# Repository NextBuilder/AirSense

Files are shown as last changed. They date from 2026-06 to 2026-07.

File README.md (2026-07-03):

<div align="center">

<br/>

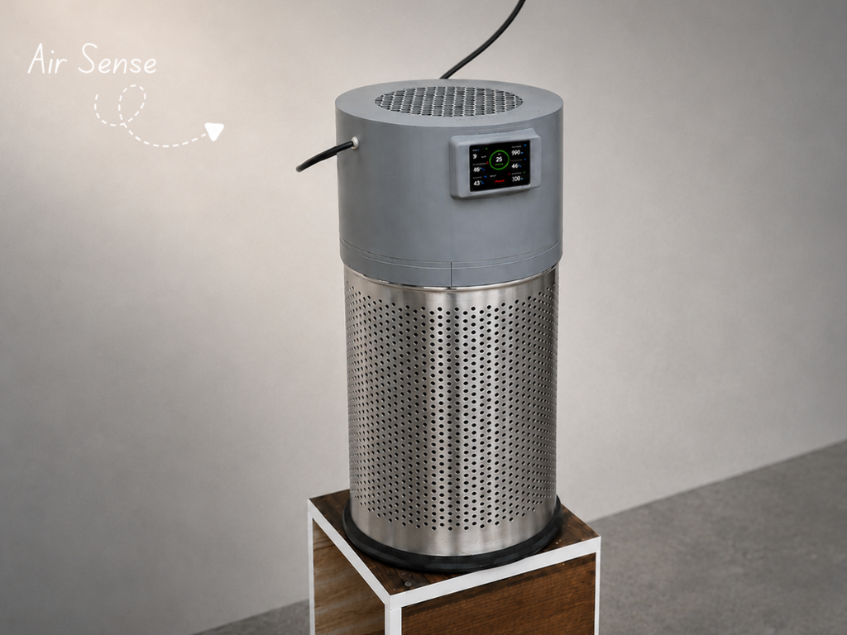
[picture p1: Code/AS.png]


<br/><br/>

# Air Sense

**The Smartest DIY Air Purifier — Engineered from Scratch**

<br/>

youtube (https://youtube.com/@NextBuilderIO)
instagram (https://instagram.com/next_builder)
x (https://x.com/NEXTBUILDERIO)
linkedin (https://www.linkedin.com/company/nextbuilderIO/)
instructables (https://www.instructables.com/member/Next%20Builder%20DIY/)
hackster (https://hackster.io/NEXTBUILDER)
hackaday (https://hackaday.io/NextBuilder)

<br/>

</div>

---

<br/>

## 🌿 Overview

Indoor air pollution is often invisible, yet it can significantly impact our health and comfort. **AirSense** is an open-source smart air purifier that combines real-time environmental monitoring, intelligent purification, and cloud connectivity into a single device.

Powered by the **Waveshare ESP32-S3**, AirSense continuously measures **PM2.5 dust levels, temperature, humidity, atmospheric pressure, and indoor air quality** using dedicated sensors. Live data is displayed on a modern **LVGL-powered TFT dashboard** and synchronized with **Arduino IoT Cloud**, allowing remote monitoring and fan control from anywhere.

Designed in **Autodesk Fusion**, the system features a custom 3D-printed enclosure, HEPA filtration, automatic fan control, and a product-like user experience. This repository includes everything needed to build your own AirSense, including source code, CAD files, circuit diagrams, and setup instructions.

<br/>

---

<br/>

## Live Display

<div align="center">
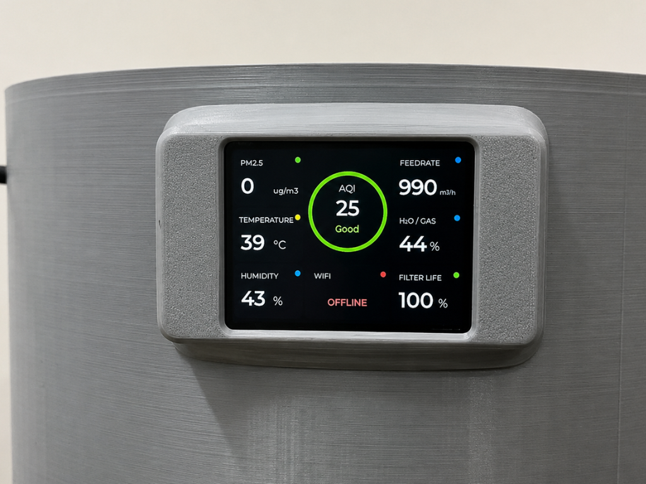
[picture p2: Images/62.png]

<br/><br/>
<sub>AirSense Live Dashboard — PM2.5 Dust · AQI · Temperature · Humidity · Air Quality · Feed Rate · Filter Health · Wi-Fi Status</sub>
</div>

<br/>

---

<br/>

## Demo

<div align="center">
<a href="https://www.youtube.com/watch?v=aSXS77vslJU">

</a>
<br/><br/>
<sub>▶ Click to watch the full build and demo on YouTube</sub>
</div>

<br/>

---

<br/>

## ✨ Features

**AirSense** combines intelligent air purification, environmental monitoring, and cloud connectivity into a single product-grade device. It continuously monitors **PM2.5 dust levels, AQI, temperature, humidity, atmospheric pressure, and indoor air quality** in real time, presenting all information through a beautiful **LVGL-powered dashboard**. The system uses a **Xiaomi Air Purifier 4 Lite HEPA filter**, capable of capturing up to **99.97% of airborne particles as small as 0.3 μm**, helping create a cleaner and healthier indoor environment.

Built around the **ESP32-S3**, AirSense synchronizes live data with **Arduino IoT Cloud**, enabling remote monitoring and control from anywhere through a smartphone, tablet, or web browser. The custom enclosure, designed in **Autodesk Fusion 360**, delivers a clean product-like appearance while maintaining easy assembly and maintenance. With complete source code, CAD files, circuit diagrams, and documentation included, AirSense is a fully open-source platform designed for learning, customization, and real-world everyday use.

<br/>

---

<br/>

## Enclosure Design

<div align="center">
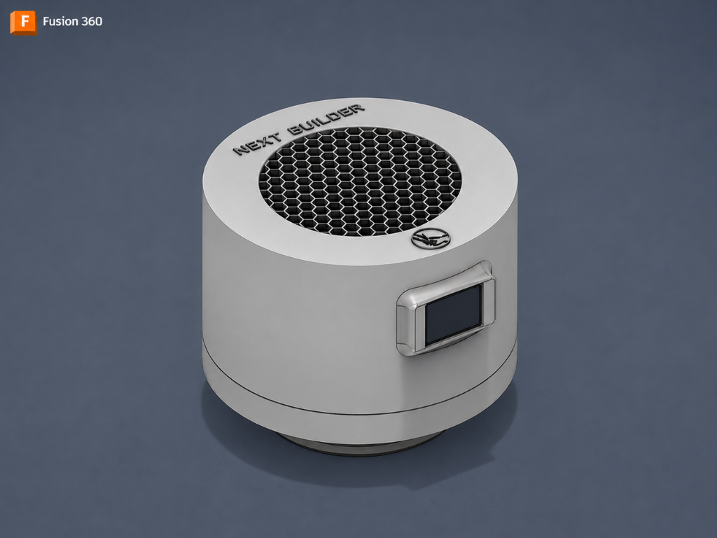
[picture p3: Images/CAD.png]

<br/><br/>
<sub>Fusion 360 CAD — cylindrical body · hexagonal intake grille · side-mounted TFT cutout · Next Builder branding</sub>
</div>

<br/>

The enclosure is designed around the **Xiaomi Air Purifier 4 Lite HEPA filter**, creating a compact and efficient airflow path. A **150mm high-airflow fan** is mounted at the top, drawing contaminated air through the filter and exhausting clean air upward. The **2.4-inch TFT display** is seamlessly integrated into a precision-cut side panel for a clean, product-like appearance. An **18L stainless steel dustbin** serves as the main structural body, providing excellent durability, a premium finish, and easy availability for replication.

<br/>

---

<br/>

## Bill of Materials

<div align="center">

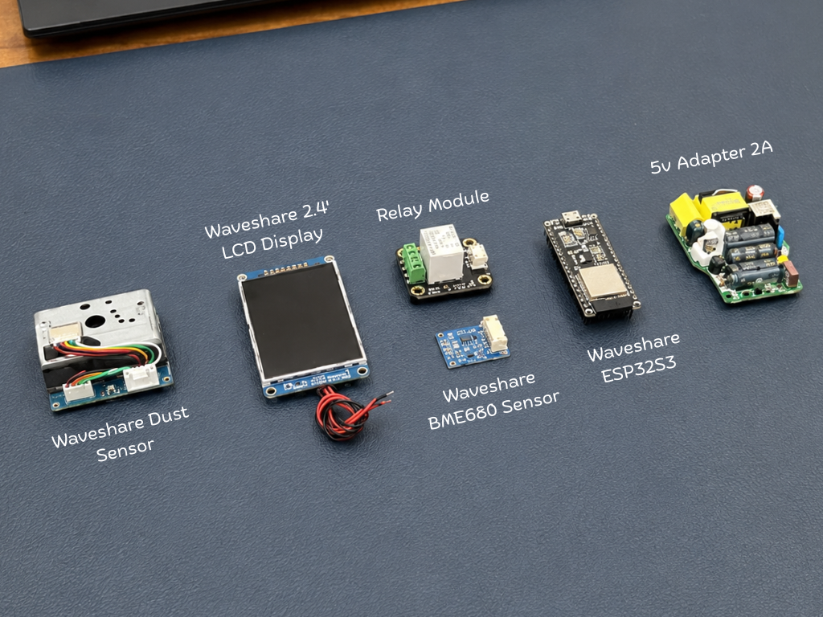
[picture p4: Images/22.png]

<br/>
<sub>All electronic components</sub>

<br/><br/>

<table>
<tr>
<td align="center" width="33%">
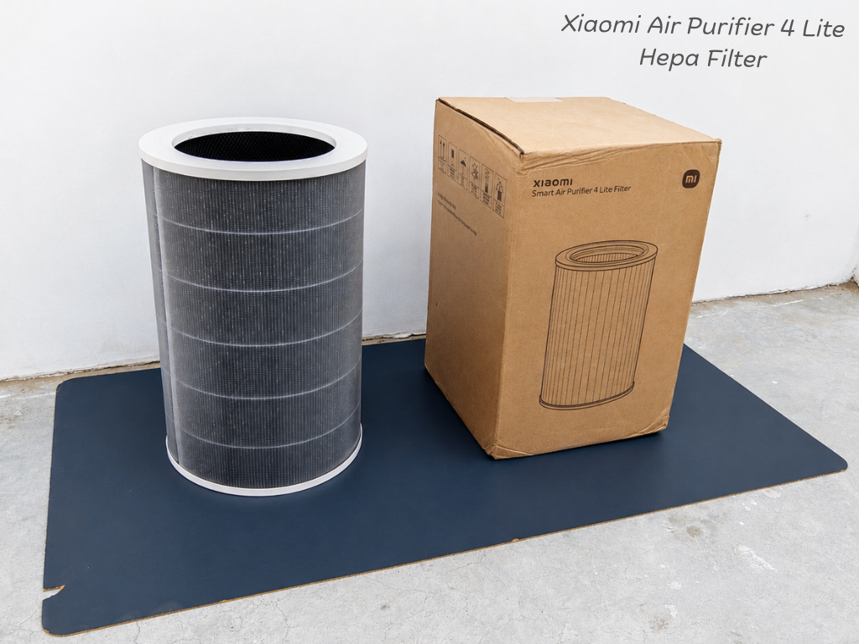
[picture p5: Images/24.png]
<br/><br/>
<b>Xiaomi Air Purifier 4 Lite</b><br/>
<sub>True HEPA Filter — 0.3 µm</sub>
</td>
<td align="center" width="33%">
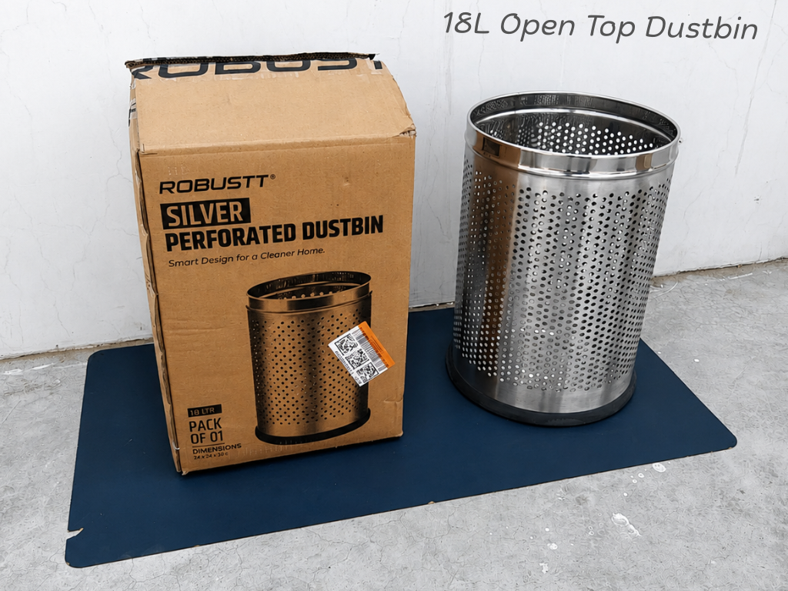
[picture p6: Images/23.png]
<br/><br/>
<b>18L Open-Top Steel Dustbin</b><br/>
<sub>Structural enclosure body</sub>
</td>
<td align="center" width="33%">
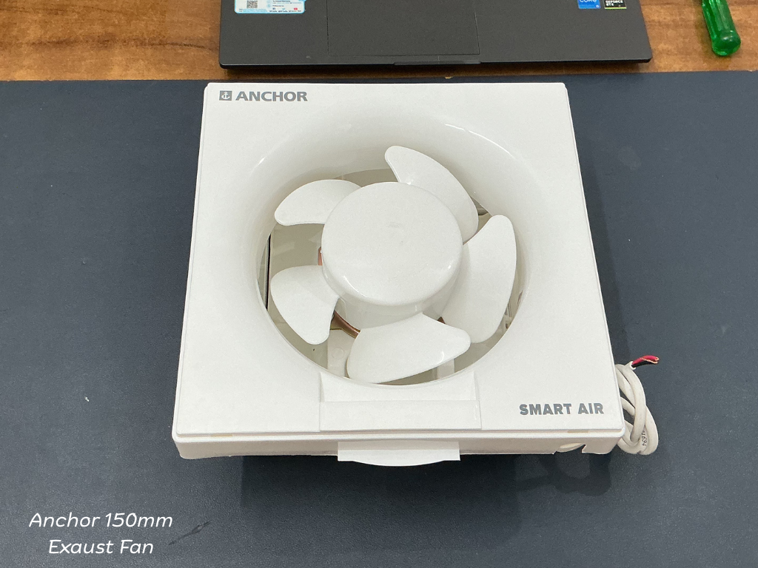
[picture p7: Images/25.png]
<br/><br/>
<b>Anchor 150mm Exhaust Fan</b><br/>
<sub>220V Smart Air — circulation</sub>
</td>
</tr>
</table>

</div>

<br/>

> Full BOM with purchase links is in the [Instructables tutorial →](https://www.instructables.com/AirSense-the-Smartest-DIY-Air-Purifier/)

<br/>

---

<br/>

## Internal Assembly

<div align="center">
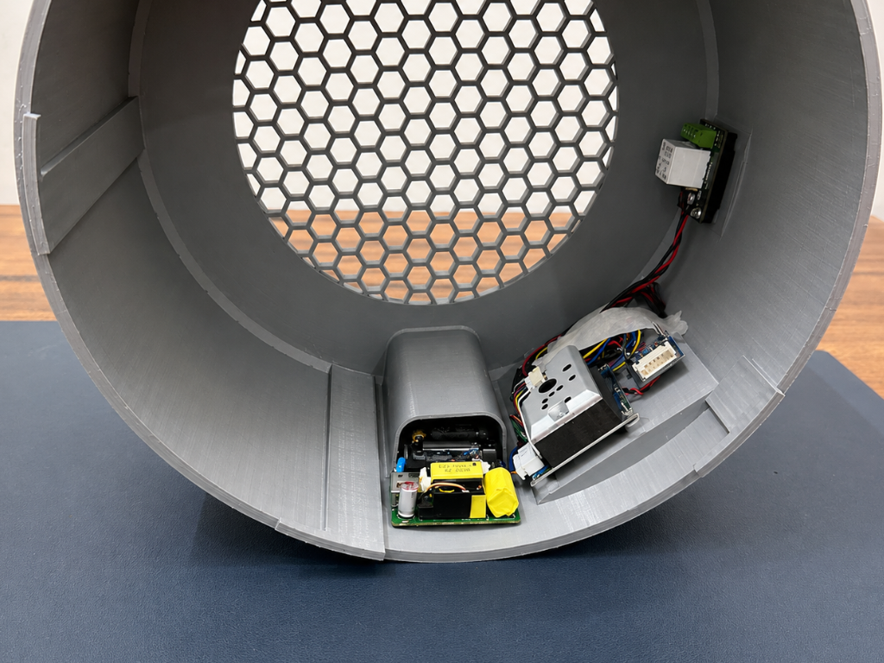
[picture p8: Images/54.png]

<br/><br/>
<sub>Inside view after complete wiring and assembly</sub>
</div>

<br/>

**Wiring Notes**

* The relay switches the **220V AC fan**, so always disconnect mains power before making any wiring changes or performing maintenance.
* The dust sensor relies on a precise LED pulse timing sequence for accurate measurements. The sampling logic used in the firmware should remain unchanged.
* The BME680 communicates via the **I²C interface**, using dedicated SDA and SCL connections on the ESP32-S3.
* The TFT display operates over **SPI**. Ensure all display pins, including CS, DC, and RST, match the assignments defined in the provided `User_Setup.h` file.
* Before powering the system, verify all power, signal, and ground connections to ensure safe and reliable operation.

<br/>

---

<br/>

## How It Works

AirSense continuously monitors the surrounding environment using dedicated air quality and environmental sensors. Every few seconds, the system measures **PM2.5 dust concentration, temperature, humidity, atmospheric pressure, and indoor air quality**, providing a real-time view of indoor environmental conditions.

The collected data is processed by the **ESP32-S3**, which calculates the Air Quality Index (AQI) and updates all measurements on the built-in **LVGL-powered dashboard**. Users can instantly view key air quality metrics through a clean and intuitive graphical interface. At the same time, sensor readings are synchronized with **Arduino IoT Cloud** over Wi-Fi, allowing remote monitoring from anywhere using a smartphone, tablet, or web browser.

The purification fan operates continuously to draw air through the **HEPA filtration system**, where dust and airborne particles are captured before clean air is released back into the environment. Users can manually turn the purifier on or off at any time using the **Arduino IoT Remote App**, providing convenient control from anywhere. By combining real-time monitoring, cloud connectivity, and continuous air purification, AirSense helps users better understand and improve the quality of the air they breathe every day.

<br/>

---

<br/>

## 📚 Build Guide & Documentation

Want to build your own **AirSense**? Complete step-by-step instructions, cloud configuration, wiring details, assembly photos, and testing procedures are available in the full written tutorials below.

Whether you're a beginner exploring IoT and air quality monitoring or an experienced maker looking to customize the design, these guides will walk you through the entire build process from start to finish.

### Tutorials & Project Documentation

* **Instructables**
  https://www.instructables.com/AirSense-the-Smartest-DIY-Air-Purifier/

* **Hackster.io**
  https://www.hackster.io/NEXTBUILDER/airsense-the-smartest-diy-air-purifier-f775f8

* **Hackaday.io**
  https://hackaday.io/project/205928-airsense-the-smartest-diy-air-purifier

* **ElectronicWings**
  https://www.electronicwings.com/users/NextBuilder/projects/6592/airsense---the-smartest-diy-air-purifier

All project resources, including firmware, CAD models, library configuration files, and circuit diagrams, are available in this GitHub repository.

---

<br/>

## License

Open for **personal and educational use only.**
Commercial use, resale, or redistribution in any product requires explicit written permission from the author.

<br/>

---

<br/>

<div align="center">

Built with ❤️ by **[Next Builder](https://youtube.com/@nextbuilderio)**

*Built one? Share it. Open an issue, tag us, drop a photo — the community makes this worth building.*

*⭐ Star this repo if it helped you build something awesome ⭐*

</div>

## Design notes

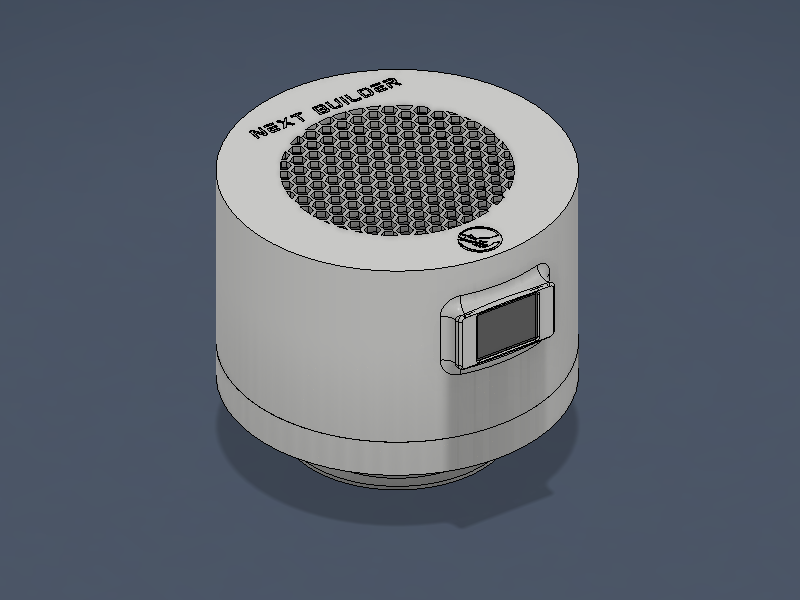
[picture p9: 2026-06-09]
CAD Design/Air Sense 01.png

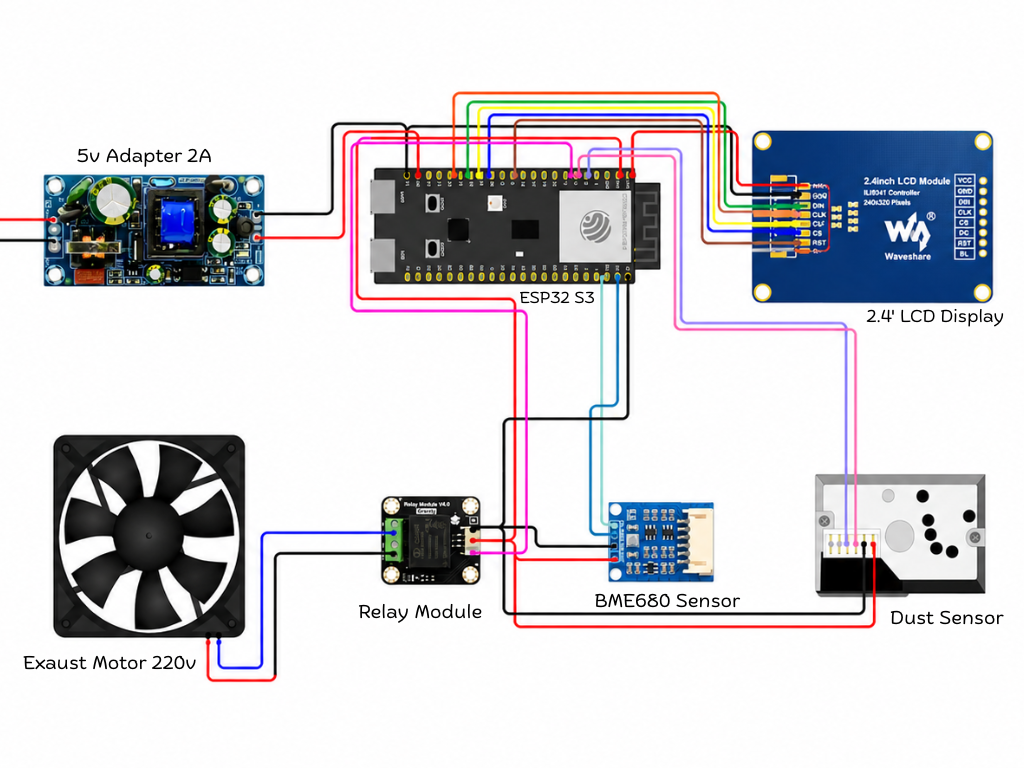
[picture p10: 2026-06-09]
Circuit Diagram/Connection Diagram.png

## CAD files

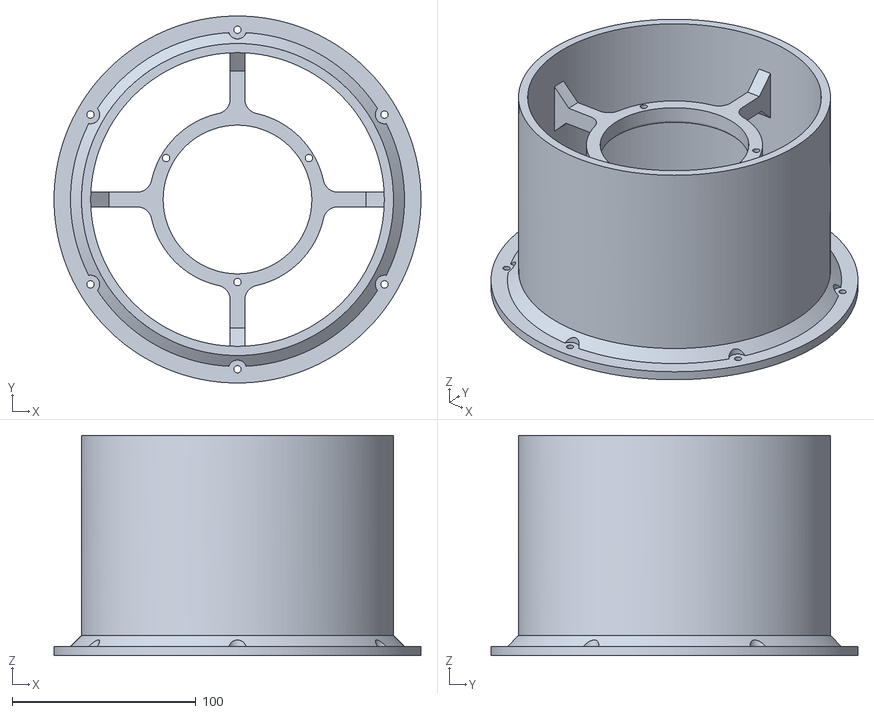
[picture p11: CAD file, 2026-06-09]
CAD Design/Motor Mount.stl
200.0 x 200.0 x 120.0

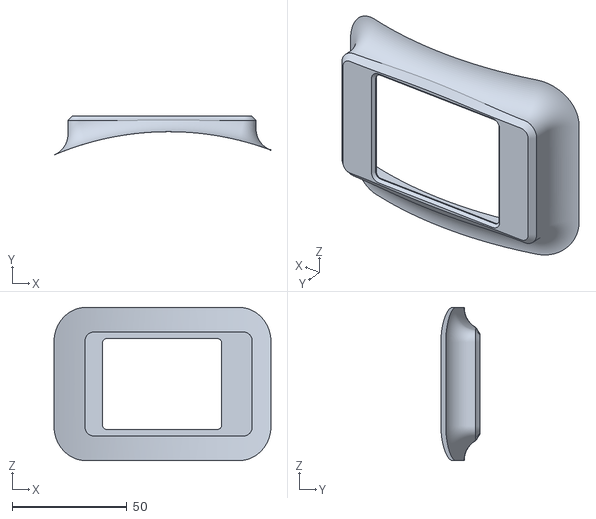
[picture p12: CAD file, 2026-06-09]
CAD Design/Display Cover.stl
94.6 x 17.1 x 66.7

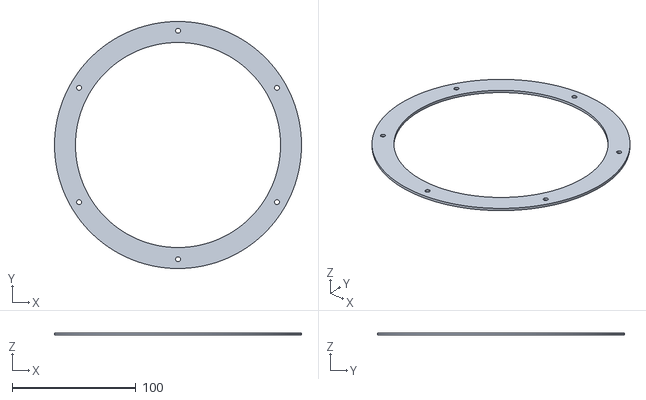
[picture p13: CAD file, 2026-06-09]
CAD Design/Gasket Seal.stl
200.0 x 200.0 x 2.00

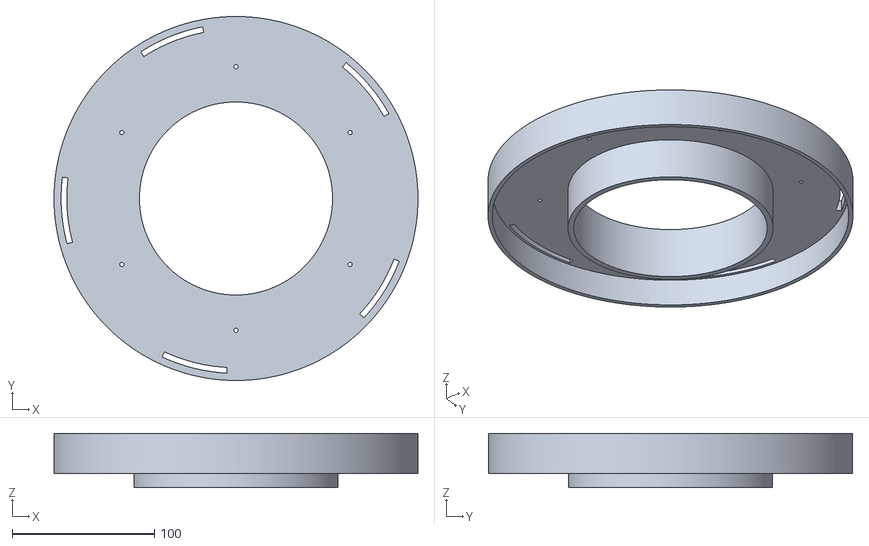
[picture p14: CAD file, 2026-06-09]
CAD Design/Bottom Plate.stl
255.5 x 255.5 x 38.0

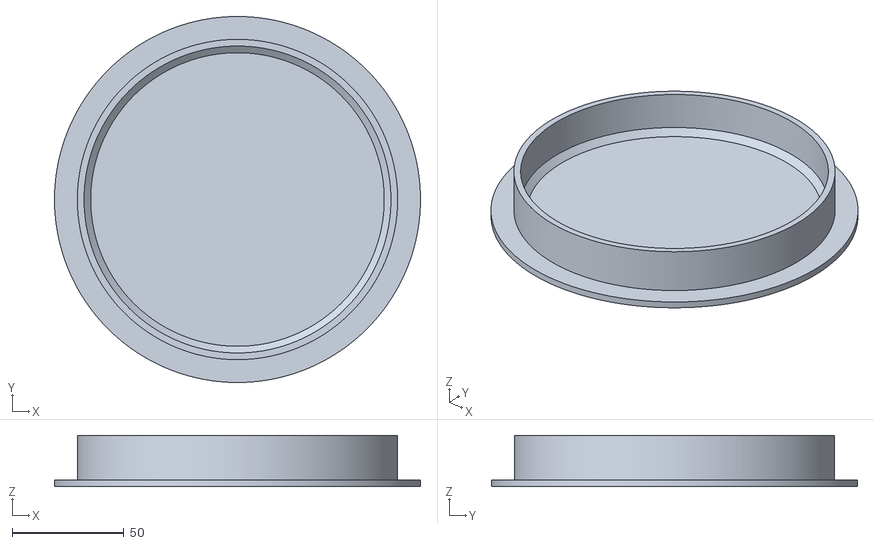
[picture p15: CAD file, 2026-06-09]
CAD Design/Filter Base.stl
164.0 x 164.0 x 23.0

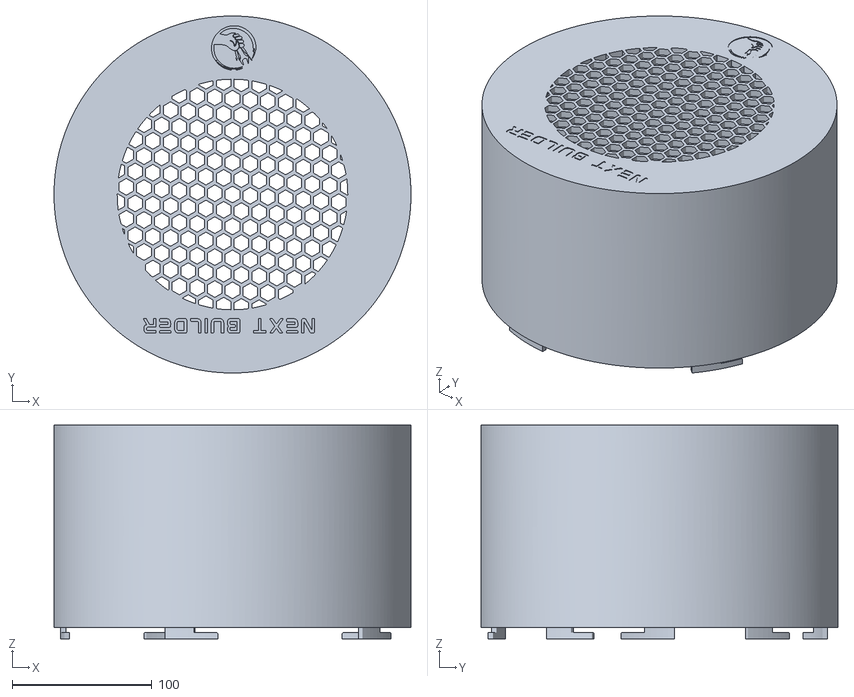
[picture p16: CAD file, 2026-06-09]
CAD Design/Housing.stl
255.5 x 255.5 x 153.0

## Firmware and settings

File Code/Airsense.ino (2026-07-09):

/**
 * ============================================================
 *  Air Sense: The Smartest DIY Air Purifier
 *  Author   : Kishan Pratap Singh
 *  Cloud    : Arduino IoT Cloud (Air Sense)
 * ============================================================
 */

// ===== INCLUDES =====
#include <Arduino.h>
#include <TFT_eSPI.h>
#include <lvgl.h>
#include <SPI.h>
#include <Adafruit_BME680.h>
#include <Wire.h>
#include <WiFi.h>
#include <ArduinoIoTCloud.h>
#include <Arduino_ConnectionHandler.h>

// ═══════════════════════════════════════════════════════════════
//  CONFIGURATION
// ═══════════════════════════════════════════════════════════════

// ── WiFi ──────────────────────────────────────────────────────
const char SSID[] = "Airtel_Nirmala Maa";
const char PASS[] = "Air@8090";

// ── IoT Cloud device credentials ───────────────────
const char THING_ID[]      = "Your_Client_ID";
const char DEVICE_LOGIN[]  = "your_device_name";              
const char DEVICE_KEY[]    = "Your_Client_Secret";

// ── Pin map ───────────────────────────────────────────────────
#define BME_SDA        43   // BME680 I2C SDA
#define BME_SCL        44   // BME680 I2C SCL

#define DUST_ILED_PIN   5   // Waveshare dust sensor — LED trigger
#define DUST_AOUT_PIN   6   // Waveshare dust sensor — analog output

#define RELAY_PIN       7   // Fan relay

// ── Polarity configuration ───────────────────────────────────
#define DUST_LED_ACTIVE_LOW 1
#if DUST_LED_ACTIVE_LOW
  #define DUST_LED_ON  LOW
  #define DUST_LED_OFF HIGH
#else
  #define DUST_LED_ON  HIGH
  #define DUST_LED_OFF LOW
#endif

#define RELAY_ACTIVE_LOW 0
#if RELAY_ACTIVE_LOW
  #define RELAY_ON  LOW
  #define RELAY_OFF HIGH
#else
  #define RELAY_ON  HIGH
  #define RELAY_OFF LOW
#endif

// ── Dust sensor calibration ──────────────────────────────────
#define DUST_SAMPLES                  15      
#define DUST_SENSITIVITY              200.0f  
#define DUST_SMOOTHING_ALPHA          0.3f    
#define DUST_DEFAULT_BASELINE         0.60f   
#define DUST_FLOOR_ADAPT_RATE         0.01f   
#define DUST_BOARD_VOLTAGE_MULTIPLIER 10.0f  
#define DUST_DEBUG                    1       

// ── BME680 gas sensor ─────────────────────────────────────────
#define BME_WARMUP_MS       300000UL  
#define IAQ_SMOOTHING_ALPHA 0.1f      

// ── Font fallback (if Inter fonts aren't generated) ──────────
#ifndef INTER_FONTS_AVAILABLE
  #define inter_bold_32    lv_font_montserrat_28
  #define inter_medium_14  lv_font_montserrat_10
  #define inter_regular_12 lv_font_montserrat_12
  #define inter_regular_16 lv_font_montserrat_14
#endif

// ═══════════════════════════════════════════════════════════════
//  DATA TYPES & AQI LOGIC
// ═══════════════════════════════════════════════════════════════

typedef struct {
  float pm25, temperature, humidity, pressure, iaq, filterLife;
  int   aqi;
  bool  wifiConnected;
} SensorData;

typedef struct { const char *label; lv_color_t color; } AQIStatus;

// EPA AQI categories, label text shortened to fit the dashboard circle.
static inline AQIStatus getAQIStatus(int aqi) {
  if (aqi <=  50) return {"Good",          lv_color_make(  0,228,  0)};   // Green
  if (aqi <= 100) return {"Moderate",      lv_color_make(255,255,  0)};   // Yellow
  if (aqi <= 150) return {"Unhealthy for\nSensitive Groups",
                                          lv_color_make(255,126,  0)};    // Orange
  if (aqi <= 200) return {"Unhealthy",     lv_color_make(255,  0,  0)};   // Red
  if (aqi <= 300) return {"Very Unhealthy",lv_color_make(143, 63,151)};   // Purple
  return              {"Hazardous",         lv_color_make(126,  0, 35)};    // Maroon
}

// EPA PM2.5 breakpoint table, extended through the Hazardous band
// (AQI 500) so severe pollution days display correctly.
static inline int calcAQI(float pm25, float iaq) {
  int p = 0;
  if      (pm25 <= 12.0f)   p = (int)(pm25 / 12.0f * 50);
  else if (pm25 <= 35.4f)   p = 51  + (int)((pm25 - 12.1f)  / 23.3f  * 49);
  else if (pm25 <= 55.4f)   p = 101 + (int)((pm25 - 35.5f)  / 19.9f  * 49);
  else if (pm25 <= 150.4f)  p = 151 + (int)((pm25 - 55.5f)  / 94.9f  * 49);
  else if (pm25 <= 250.4f)  p = 201 + (int)((pm25 - 150.5f) / 99.9f  * 99);
  else if (pm25 <= 500.4f)  p = 301 + (int)((pm25 - 250.5f) / 249.9f * 199);
  else                      p = 500;
  return (int)(p*0.7f + (100.f-iaq)*1.5f*0.3f);
}

// ═══════════════════════════════════════════════════════════════
//  UI THEME & LAYOUT CONSTANTS
// ═══════════════════════════════════════════════════════════════

#define CB    lv_color_hex(0x050505)
#define CC    lv_color_hex(0x111111)
#define CD    lv_color_hex(0x232323)
#define CW    lv_color_hex(0xFFFFFF)
#define CG    lv_color_hex(0x00DF50)
#define CGD1  lv_color_hex(0x003D18)
#define CGD2  lv_color_hex(0x001E0C)
#define CGD3  lv_color_hex(0x000D05)
#define CDIM  lv_color_hex(0x757575)
#define CR    10

#define CSW   96
#define CH    75
#define XL     2
#define XR   222
#define XC   101
#define WC   118
#define Y1     2
#define Y2    80
#define Y3   158

#define AQI_CX  160
#define AQI_CY   86
#define AQI_R   109

#define SCREEN_W 320
#define SCREEN_H 240
#define BUF_SIZE (SCREEN_W * 24)

// ═══════════════════════════════════════════════════════════════
//  DISPLAY & LVGL CORE
// ═══════════════════════════════════════════════════════════════

static lv_color_t buf1[BUF_SIZE];
static lv_color_t buf2[BUF_SIZE];
TFT_eSPI tft = TFT_eSPI();

void lvgl_flush_cb(lv_display_t *d, const lv_area_t *a, uint8_t *px) {
  tft.startWrite();
  tft.setAddrWindow(a->x1, a->y1, a->x2-a->x1+1, a->y2-a->y1+1);
  tft.pushColors((uint16_t*)px, (a->x2-a->x1+1)*(a->y2-a->y1+1), true);
  tft.endWrite();
  lv_display_flush_ready(d);
}

void IRAM_ATTR lvgl_tick() { lv_tick_inc(1); }

void initDisplay() {
  tft.begin();
  tft.setRotation(1);
  tft.fillScreen(TFT_BLACK);
}

void initLVGL() {
  lv_init();
  lv_display_t *disp = lv_display_create(SCREEN_W, SCREEN_H);

  lv_display_set_buffers(disp, buf1, buf2, sizeof(buf1), LV_DISPLAY_RENDER_MODE_PARTIAL);
  lv_display_set_flush_cb(disp, lvgl_flush_cb);

#if defined(ESP_ARDUINO_VERSION_MAJOR) && ESP_ARDUINO_VERSION_MAJOR >= 3
  hw_timer_t *tmr = timerBegin(1000000);          // 1 MHz
  timerAttachInterrupt(tmr, &lvgl_tick);
  timerAlarm(tmr, 1000, true, 0);                 // 1 ms tick
#else
  hw_timer_t *tmr = timerBegin(0, 80, true);      // 80MHz 
  timerAttachInterrupt(tmr, &lvgl_tick, true);
  timerAlarmWrite(tmr, 1000, true);
  timerAlarmEnable(tmr);
#endif
}

// ═══════════════════════════════════════════════════════════════
//  UI WIDGET HANDLES
// ═══════════════════════════════════════════════════════════════

lv_obj_t *ui_glow_arc   = NULL;
lv_obj_t *ui_aqi_arc    = NULL;
lv_obj_t *ui_aqi_value  = NULL;
lv_obj_t *ui_aqi_status = NULL;
lv_obj_t *ui_aqi_label  = NULL;

lv_obj_t *ui_pm25_val   = NULL;
lv_obj_t *ui_temp_val   = NULL;
lv_obj_t *ui_hum_val    = NULL;
lv_obj_t *ui_pres_val   = NULL;
lv_obj_t *ui_iaq_val    = NULL;
lv_obj_t *ui_filter_val = NULL;
lv_obj_t *ui_filter_status_label = NULL;
lv_obj_t *ui_wifi_label = NULL;
lv_obj_t *ui_wifi_dot   = NULL;

// ═══════════════════════════════════════════════════════════════
//  UI BUILDER HELPERS
// ═══════════════════════════════════════════════════════════════

static lv_obj_t* mkCard(lv_obj_t *p, lv_coord_t x, lv_coord_t y,
                          lv_coord_t w, lv_coord_t h) {
  lv_obj_t *c = lv_obj_create(p);
  lv_obj_set_pos(c,x,y); lv_obj_set_size(c,w,h);
  lv_obj_clear_flag(c, LV_OBJ_FLAG_SCROLLABLE);
  lv_obj_set_scrollbar_mode(c, LV_SCROLLBAR_MODE_OFF);
  lv_obj_set_style_bg_color(c,     CC,           0);
  lv_obj_set_style_bg_opa(c,       LV_OPA_COVER, 0);
  lv_obj_set_style_border_color(c, CD,           0);
  lv_obj_set_style_border_width(c, 1,            0);
  lv_obj_set_style_border_opa(c,   85,           0);
  lv_obj_set_style_radius(c,       CR,           0);
  lv_obj_set_style_pad_all(c,      0,            0);
  lv_obj_set_style_shadow_color(c, lv_color_hex(0x000000), 0);
  lv_obj_set_style_shadow_width(c, 8,            0);
  lv_obj_set_style_shadow_opa(c,   70,           0);
  return c;
}

static void mkDot(lv_obj_t *c, lv_coord_t cw, lv_color_t col) {
  lv_obj_t *d = lv_obj_create(c);
  lv_obj_set_size(d,6,6); lv_obj_set_pos(d, cw-11, 9);
  lv_obj_set_style_bg_color(d,    col,              0);
  lv_obj_set_style_bg_opa(d,      LV_OPA_COVER,     0);
  lv_obj_set_style_radius(d,      LV_RADIUS_CIRCLE, 0);
  lv_obj_set_style_border_width(d, 0,               0);
  lv_obj_set_style_pad_all(d,     0,                0);
}

static void mkTitle(lv_obj_t *c, const char *t, lv_coord_t x) {
  lv_obj_t *l = lv_label_create(c);
  lv_label_set_text(l, t);
  lv_obj_set_style_text_color(l, CDIM,                   0);
  lv_obj_set_style_text_font(l,  &inter_medium_14,       0);
  lv_obj_set_pos(l, x, 11);
}

static lv_obj_t* mkVal(lv_obj_t *c, const char *v, const char *u,
                         const lv_font_t *f,
                         const lv_font_t *unit_font,
                         lv_coord_t vx, lv_coord_t vy,
                         lv_coord_t unit_off_x = 6) {
  lv_obj_t *vl = lv_label_create(c);
  lv_label_set_text(vl, v);
  lv_obj_set_style_text_color(vl, CW, 0);
  lv_obj_set_style_text_font(vl,  f,  0);
  lv_obj_set_pos(vl, vx, vy);

  lv_obj_t *ul = lv_label_create(c);
  lv_label_set_text(ul, u);
  lv_obj_set_style_text_color(ul, CDIM,                   0);
  lv_obj_set_style_text_font(ul,  unit_font,              0);
  lv_obj_align_to(ul, vl, LV_ALIGN_OUT_RIGHT_BOTTOM, unit_off_x, -3);
  return vl;
}

static lv_obj_t* metCard(lv_obj_t *p,
                           lv_coord_t x, lv_coord_t y, lv_coord_t w,
                           const char *ttl,
                           const char *val, const char *unit,
                           const lv_font_t *fnt,
                           const lv_font_t *unit_fnt,
                           lv_coord_t vx, lv_coord_t vy,
                           lv_color_t dotCol,
                           lv_coord_t title_x,
                           lv_coord_t unit_off_x = 6) {
  lv_obj_t *c = mkCard(p, x, y, w, CH);
  mkDot(c, w, dotCol);
  mkTitle(c, ttl, title_x);
  return mkVal(c, val, unit, fnt, unit_fnt, vx, vy, unit_off_x);
}

// ═══════════════════════════════════════════════════════════════
//  DASHBOARD WIDGETS
// ═══════════════════════════════════════════════════════════════

static void buildAQI(lv_obj_t *scr, int aqi) {
  AQIStatus st = getAQIStatus(aqi);
  const lv_coord_t cx=AQI_CX, cy=AQI_CY, r=AQI_R;

  auto glowArc = [&](lv_coord_t dia, lv_color_t col,
                      lv_opa_t opa, int w) -> lv_obj_t* {
    lv_obj_t *a = lv_arc_create(scr);
    lv_obj_set_size(a, dia, dia);
    lv_obj_set_pos(a, cx-dia/2, cy-dia/2);
    lv_arc_set_angles(a,    0, 360);
    lv_arc_set_bg_angles(a, 0, 360);
    lv_obj_set_style_arc_color(a, col, LV_PART_INDICATOR);
    lv_obj_set_style_arc_color(a, col, LV_PART_MAIN);
    lv_obj_set_style_arc_width(a, w,   LV_PART_INDICATOR);
    lv_obj_set_style_arc_width(a, w,   LV_PART_MAIN);
    lv_obj_set_style_arc_opa(a,  opa,  LV_PART_INDICATOR);
    lv_obj_set_style_arc_opa(a,  opa,  LV_PART_MAIN);
    lv_obj_remove_style(a, NULL, LV_PART_KNOB);
    lv_obj_set_style_bg_opa(a,   LV_OPA_TRANSP, 0);
    lv_obj_set_style_border_width(a, 0, 0);
    return a;
  };

  ui_glow_arc = glowArc(r+2, CGD1, 130, 10);

  lv_coord_t fi = r - 10;
  lv_obj_t *f = lv_obj_create(scr);
  lv_obj_set_size(f, fi, fi);
  lv_obj_set_pos(f, cx-fi/2, cy-fi/2);
  lv_obj_set_style_bg_color(f,    lv_color_hex(0x060606), 0);
  lv_obj_set_style_bg_opa(f,      LV_OPA_COVER,           0);
  lv_obj_set_style_radius(f,      LV_RADIUS_CIRCLE,       0);
  lv_obj_set_style_border_width(f, 0, 0);
  lv_obj_set_style_pad_all(f,     0, 0);
  lv_obj_clear_flag(f, LV_OBJ_FLAG_SCROLLABLE);

  ui_aqi_arc = lv_arc_create(scr);
  lv_obj_set_size(ui_aqi_arc, r, r);
  lv_obj_set_pos(ui_aqi_arc, cx-r/2, cy-r/2);
  lv_arc_set_angles(ui_aqi_arc,    0, 360);
  lv_arc_set_bg_angles(ui_aqi_arc, 0, 360);
  lv_obj_set_style_arc_color(ui_aqi_arc, st.color,                LV_PART_INDICATOR);
  lv_obj_set_style_arc_color(ui_aqi_arc, lv_color_hex(0x181818),  LV_PART_MAIN);
  lv_obj_set_style_arc_width(ui_aqi_arc, 4, LV_PART_INDICATOR);
  lv_obj_set_style_arc_width(ui_aqi_arc, 4, LV_PART_MAIN);
  lv_obj_remove_style(ui_aqi_arc, NULL, LV_PART_KNOB);
  lv_obj_set_style_bg_opa(ui_aqi_arc, LV_OPA_TRANSP, 0);
  lv_obj_set_style_border_width(ui_aqi_arc, 0, 0);

  ui_aqi_label = lv_label_create(scr);
  lv_label_set_text(ui_aqi_label, "AQI");
  lv_obj_set_style_text_color(ui_aqi_label, CDIM,                   0);
  lv_obj_set_style_text_font(ui_aqi_label,  &inter_regular_12,      0);
  lv_obj_set_width(ui_aqi_label, WC);
  lv_obj_set_style_text_align(ui_aqi_label, LV_TEXT_ALIGN_CENTER,   0);
  lv_obj_set_pos(ui_aqi_label, XC, cy-40);

  ui_aqi_value = lv_label_create(scr);
  char nb[8]; snprintf(nb, 8, "%d", aqi);
  lv_label_set_text(ui_aqi_value, nb);
  lv_obj_set_style_text_color(ui_aqi_value, CW,                    0);
  lv_obj_set_style_text_font(ui_aqi_value,  &inter_bold_32,        0);
  lv_obj_set_width(ui_aqi_value, WC);
  lv_obj_set_style_text_align(ui_aqi_value, LV_TEXT_ALIGN_CENTER,  0);
  lv_obj_set_pos(ui_aqi_value, XC, cy-21);

  ui_aqi_status = lv_label_create(scr);
  lv_label_set_text(ui_aqi_status, st.label);
  lv_obj_set_style_text_color(ui_aqi_status, st.color,               0);
  lv_obj_set_style_text_font(ui_aqi_status,  &inter_regular_12,      0);
  lv_obj_set_width(ui_aqi_status, WC);
  lv_label_set_long_mode(ui_aqi_status, LV_LABEL_LONG_WRAP);
  lv_obj_set_style_text_align(ui_aqi_status, LV_TEXT_ALIGN_CENTER,   0);
  lv_obj_set_pos(ui_aqi_status, XC, cy+15);
}

static void buildWifi(lv_obj_t *scr, bool conn) {
  lv_obj_t *c = mkCard(scr, XC, Y3, WC, CH);

  ui_wifi_dot = lv_obj_create(c);
  lv_obj_set_size(ui_wifi_dot, 6, 6);
  lv_obj_set_pos(ui_wifi_dot, WC-13, 9);
  lv_obj_set_style_bg_color(ui_wifi_dot, conn?CG:lv_color_hex(0xFF4444), 0);
  lv_obj_set_style_bg_opa(ui_wifi_dot,   LV_OPA_COVER,     0);
  lv_obj_set_style_radius(ui_wifi_dot,   LV_RADIUS_CIRCLE, 0);
  lv_obj_set_style_border_width(ui_wifi_dot, 0,            0);
  lv_obj_set_style_pad_all(ui_wifi_dot,  0,                0);

  lv_obj_t *sub = lv_label_create(c);
  lv_label_set_text(sub, "WIFI");
  lv_obj_set_style_text_color(sub, CDIM,                   0);
  lv_obj_set_style_text_font(sub,  &inter_medium_14,       0);
  lv_obj_set_pos(sub, 12, 10);

  ui_wifi_label = lv_label_create(c);
  lv_label_set_text(ui_wifi_label, conn ? "CONNECTED" : "OFFLINE");
  lv_obj_set_style_text_color(ui_wifi_label,
    conn ? CW : lv_color_hex(0xFF4444), 0);
  lv_obj_set_style_text_font(ui_wifi_label, &inter_regular_12, 0);
  lv_obj_set_pos(ui_wifi_label, 5, 44);
  lv_obj_set_width(ui_wifi_label, WC-11);
  lv_obj_set_style_text_align(ui_wifi_label, LV_TEXT_ALIGN_CENTER, 0);
}

void createDashboard(const SensorData *d) {
  lv_obj_t *scr = lv_screen_active();
  lv_obj_set_style_bg_color(scr, CB,           0);
  lv_obj_set_style_bg_opa(scr,   LV_OPA_COVER, 0);
  lv_obj_clear_flag(scr, LV_OBJ_FLAG_SCROLLABLE);

  char b[16];

  snprintf(b,16,"%.0f",d->pm25);
  ui_pm25_val = metCard(scr,XL,Y1,CSW,
    "PM2.5",b,"ug/m3",
    &inter_bold_32, &inter_medium_14,
    9,32,lv_color_hex(0x00DF50),
    9, 26);

  snprintf(b,16,"%.0f",d->temperature);
  ui_temp_val = metCard(scr,XL,Y2,CSW,
    "TEMPERATURE",b,"\xC2\xB0""C",
    &inter_bold_32, &lv_font_montserrat_16,
    9,32,lv_color_hex(0xFFAA33),
    4, 26);

  snprintf(b,16,"%.0f",d->humidity);
  ui_hum_val = metCard(scr,XL,Y3,CSW,
    "HUMIDITY",b,"%",
    &inter_bold_32, &lv_font_montserrat_16,
    9,32,lv_color_hex(0x3399FF),
    9, 26);

  snprintf(b,16,"%.0f",d->pressure);
  ui_pres_val = metCard(scr,XR,Y1,CSW,
    "PRESSURE",b,"hPa",
    &inter_bold_32, &inter_medium_14,
    7,34,lv_color_hex(0x9977FF),
    9, 37);

  snprintf(b,16,"%.0f",d->iaq);
  ui_iaq_val = metCard(scr,XR,Y2,CSW,
    "IAQ / GAS",b,"%",
    &inter_bold_32, &lv_font_montserrat_16,
    9,32,lv_color_hex(0x3399FF),
    9);

  snprintf(b,16,"%.0f",d->filterLife);
  ui_filter_val = metCard(scr,XR,Y3,CSW,
    "FILTER LIFE",b,"%",
    &inter_bold_32, &lv_font_montserrat_16,
    9,32,lv_color_hex(0x00DF50),
    9);

  lv_obj_t *filterCard = lv_obj_get_parent(ui_filter_val);
  ui_filter_status_label = lv_label_create(filterCard);
  lv_label_set_text(ui_filter_status_label, "");
  lv_obj_set_style_text_font(ui_filter_status_label, &inter_regular_12, 0);
  lv_obj_set_style_text_color(ui_filter_status_label, lv_color_hex(0xFF4444), 0);
  lv_obj_align_to(ui_filter_status_label, ui_filter_val, LV_ALIGN_OUT_BOTTOM_LEFT, 0, 3);

  buildAQI(scr, d->aqi);
  buildWifi(scr, d->wifiConnected);
}

void updateSensorValues(const SensorData *d) {
  char b[16];
  AQIStatus st = getAQIStatus(d->aqi);

  auto upd = [](lv_obj_t *l, const char *t){ if(l) lv_label_set_text(l,t); };
  snprintf(b,16,"%.0f",d->pm25);        upd(ui_pm25_val,   b);
  snprintf(b,16,"%.0f",d->temperature); upd(ui_temp_val,   b);
  snprintf(b,16,"%.0f",d->humidity);    upd(ui_hum_val,    b);
  snprintf(b,16,"%.0f",d->pressure);    upd(ui_pres_val,   b);
  snprintf(b,16,"%.0f",d->iaq);         upd(ui_iaq_val,    b);
  snprintf(b,16,"%.0f",d->filterLife);  upd(ui_filter_val, b);

  const char* filterMsg = "";
  if (d->filterLife <= 10)      filterMsg = "Replace Filter";
  else if (d->filterLife <= 20) filterMsg = "Replace Soon";
  if (ui_filter_status_label) lv_label_set_text(ui_filter_status_label, filterMsg);

  if (ui_aqi_value)  { snprintf(b,16,"%d",d->aqi); lv_label_set_text(ui_aqi_value,b); }
  if (ui_aqi_status) { lv_label_set_text(ui_aqi_status, st.label);
                       lv_obj_set_style_text_color(ui_aqi_status, st.color, 0); }
  if (ui_aqi_arc)
    lv_obj_set_style_arc_color(ui_aqi_arc, st.color, LV_PART_INDICATOR);
  if (ui_wifi_label) {
    lv_label_set_text(ui_wifi_label, d->wifiConnected?"CONNECTED":"OFFLINE");
    lv_obj_set_style_text_color(ui_wifi_label,
      d->wifiConnected?CW:lv_color_hex(0xFF4444), 0);
  }
  if (ui_wifi_dot)
    lv_obj_set_style_bg_color(ui_wifi_dot,
      d->wifiConnected?CG:lv_color_hex(0xFF4444), 0);
}

// ═══════════════════════════════════════════════════════════════
//  UI ANIMATIONS
// ═══════════════════════════════════════════════════════════════

static uint16_t s_glowPhase = 0;
static uint16_t s_wifiPhase = 0;

static uint8_t smoothPulse(uint16_t phase, uint16_t total) {
  uint32_t p = (uint32_t)phase * 512 / total;
  if (p > 255) p = 511 - p;
  uint32_t x = p;
  uint32_t y = x*x*(767 - 2*x) / 65536;
  return (uint8_t)(y > 255 ? 255 : y);
}
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
void loop() {
  unsigned long now = millis();

  ArduinoCloud.update();
  lv_timer_handler();

  updateFanRuntime();
  g_data.filterLife = calculateFilterLife();

  if (now - tAnim >= 16) {
    tAnim = now;
    animateGlow();
    animateWiFi();
  }

  if (now - tSensor >= 2000) {
    tSensor = now;

    if (bme680_ok && bme.performReading()) {
      g_data.temperature = bme.temperature;
      g_data.humidity    = bme.humidity;
      g_data.pressure    = bme.pressure / 100.0f;

      float gas = bme.gas_resistance / 1000.0f;
      float iaqPercent = 0;
      if (gas > 200) iaqPercent = 100;
      else if (gas < 10) iaqPercent = 0;
      else iaqPercent = (gas - 10) * 100.0f / (200.0f - 10.0f);
      iaqPercent = constrain(iaqPercent, 0, 100);

      if (now < BME_WARMUP_MS) {
        
        g_data.iaq = 50;
      } else {
        static float iaqFiltered = -1;
        if (iaqFiltered < 0) iaqFiltered = iaqPercent;
        iaqFiltered += IAQ_SMOOTHING_ALPHA * (iaqPercent - iaqFiltered);
        g_data.iaq = iaqFiltered;
      }
    } else if (!bme680_ok) {
      g_data.temperature = 0;
      g_data.humidity    = 0;
      g_data.pressure    = 0;
      g_data.iaq         = 50;
    }

    g_data.pm25          = readDustSensor();
    g_data.wifiConnected = (WiFi.status() == WL_CONNECTED);
    g_data.aqi            = calcAQI(g_data.pm25, g_data.iaq);

    updateSensorValues(&g_data);

    DUST        = g_data.pm25;
    Temperature = g_data.temperature;
    Humidity    = g_data.humidity;
    AQI         = g_data.aqi;

  }

  delay(4);
}

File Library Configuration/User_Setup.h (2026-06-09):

/**
 * User_Setup.h — TFT_eSPI configuration
 * ─────────────────────────────────────
 * COPY THIS FILE TO:
 *   Arduino/libraries/TFT_eSPI/User_Setup.h
 *   (overwrite/replace the existing one)
 *
 * Hardware : ESP32-S3-Zero + Waveshare 2.4" ILI9341
 * Pins     : CONFIRMED WORKING
 */

#define USER_SETUP_ID 70
#define USER_SETUP_LOADED

// ─── DRIVER ──────────────────────────────────────────────────
#define ILI9341_DRIVER

// ─── DISPLAY SIZE (portrait native, rotated in code) ─────────
#define TFT_WIDTH   240
#define TFT_HEIGHT  320

// ─── HSPI PORT (required for ESP32-S3) ───────────────────────
#define USE_HSPI_PORT

// ─── PIN DEFINITIONS ─────────────────────────────────────────
#define TFT_MOSI  11    // DIN
#define TFT_SCLK  12    // CLK
#define TFT_CS    10    // CS
#define TFT_DC     9    // DC
#define TFT_RST    8    // RST
#define TFT_MISO  -1    // Not connected
#define TFT_BL    -1    // Backlight hard-wired to 3V3

// ─── SPI SPEED ───────────────────────────────────────────────
#define SPI_FREQUENCY        40000000
#define SPI_READ_FREQUENCY    6000000
#define SPI_TOUCH_FREQUENCY   2500000

// ─── FONTS ───────────────────────────────────────────────────
#define LOAD_GLCD
#define LOAD_FONT2
#define LOAD_FONT4
#define LOAD_FONT6
#define LOAD_FONT7
#define LOAD_FONT8
#define LOAD_GFXFF
#define SMOOTH_FONT

// ─── REQUIRED ────────────────────────────────────────────────
#define SUPPORT_TRANSACTIONS
